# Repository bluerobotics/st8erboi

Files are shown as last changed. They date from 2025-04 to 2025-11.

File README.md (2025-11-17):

<div align="center">

Fillhead

# Fillhead

**Material Injection System Control**






[View Changelog](CHANGELOG.md) • [Download Latest Release](https://github.com/bluerobotics/fillhead/releases/latest)

</div>

---

## Overview

Firmware for the Fillhead material injection system, built on the Teknic ClearCore platform. This firmware provides precision control for material injection operations with dual-motor injector control, pinch valve management, temperature control, and vacuum system monitoring.

**Designed to work with:** [BR Equipment Control App](https://github.com/bluerobotics/br-equipment-control-app) - A Python/Tkinter GUI for controlling and monitoring the Fillhead and other Blue Robotics manufacturing equipment.

## Features

- **Dual injector motors** - Synchronized control of two ganged motors for material injection
- **Pinch valve control** - Two independent motorized pinch valves (vacuum and injection sides)
- **Temperature control** - PID-based heater control with thermocouple feedback
- **Vacuum system** - Pressure monitoring and control with transducer feedback
- **UDP/Ethernet communication** - Network-based control with device discovery
- **USB Serial fallback** - Direct USB communication support
- **Command-based control** - Simple text-based command protocol
- **Real-time telemetry** - Position, temperature, pressure, torque, and status reporting
- **Homing routines** - Automatic homing for injector and pinch valves (tubed/untubed modes)
- **Leak testing** - Automated vacuum leak detection

---

## Building

### Requirements

- **Atmel Studio 7** (Windows) or compatible ARM GCC toolchain
- **Teknic ClearCore libraries** (included in `lib/` folder)
  - `libClearCore`
  - `LwIP` (Lightweight IP stack)

### Build Instructions

1. Open `fillhead.atsln` in Atmel Studio
2. Ensure libraries are properly referenced:
   - `lib/libClearCore/ClearCore.cppproj`
   - `lib/LwIP/LwIP.cppproj`
3. Select build configuration (Debug or Release)
4. Build the solution (F7)

### Output Files

- `Debug/fillhead.bin` - Binary firmware image
- `Debug/fillhead.uf2` - UF2 format for bootloader flashing

## Flashing

### Via BR Equipment Control App (Recommended for Updates)

The easiest way to update firmware on an already-running device is through the [BR Equipment Control App](https://github.com/bluerobotics/br-equipment-control-app):

1. Open the Firmware Manager in the app
2. Select your device
3. Choose the firmware file or download the latest release
4. Click "Update Firmware" - the app handles the entire flashing process automatically

**Note:** Firmware flashing is only supported over USB connections. For initial flashing of a new device, use the bootloader method below.

### Via Bootloader (For Initial Flashing)

For initial flashing of a new device or when the app is not available:

1. Put the ClearCore into bootloader mode (hold button during power-on)
2. Copy `fillhead.uf2` to the mounted bootloader drive
3. The device will automatically reboot with new firmware

### Via Atmel Studio

1. Connect ClearCore via USB
2. Select "Custom Programming Tool" in project settings
3. Build and program (F5)

---

## Communication Protocol

The firmware uses a simple text-based command protocol over UDP or USB serial:

- Commands: `inject <volume> ml`, `feed <distance> mm`, `home_injector`, `set_heater <temp> C`
- Status: `DONE: <command>`, `ERROR: <message>`, `INFO: <message>`
- Telemetry: Periodic status updates with position, temperature, pressure, torque

See the [BR Equipment Control App](https://github.com/bluerobotics/br-equipment-control-app) for full protocol documentation and command reference.

---

## Hardware Configuration

### Motors
- **Injector A**: Primary injector motor (M0)
- **Injector B**: Secondary injector motor (M1) - ganged with A
- **Vacuum Valve**: Pinch valve motor for vacuum side (M2)
- **Injection Valve**: Pinch valve motor for injection side (M3)

### Sensors
- **Thermocouple**: Analog input (A12) for temperature monitoring
- **Vacuum Transducer**: Analog input (A11) for pressure monitoring

### Outputs
- **Heater Relay**: Digital output (IO1) for heater control
- **Vacuum Pump Relay**: Digital output (IO0) for vacuum pump control
- **Vacuum Solenoid Relay**: Digital output (IO5) for solenoid valve control

## Configuration

Key parameters can be configured in `inc/config.h`:

- **Motor parameters**: Steps per mm, velocities, accelerations
- **Temperature control**: PID gains, setpoints, sensor calibration
- **Vacuum control**: Pressure ranges, targets, ramp timeouts
- **Injection parameters**: Piston diameters, speeds, feed rates
- **Homing parameters**: Velocities, accelerations, torque limits for tubed/untubed modes
- **Network settings**: UDP port, packet sizes, telemetry interval

---

## License

This project is licensed under the MIT License - see the [LICENSE](LICENSE) file for details.

Copyright (c) 2025 Blue Robotics

## Contributing

For issues, feature requests, or contributions, please open an issue or pull request on GitHub.

---

<div align="center">

⭐ **Star us on GitHub if you found this useful!**

Made with 💙 by the Blue Robotics team and contributors worldwide

---

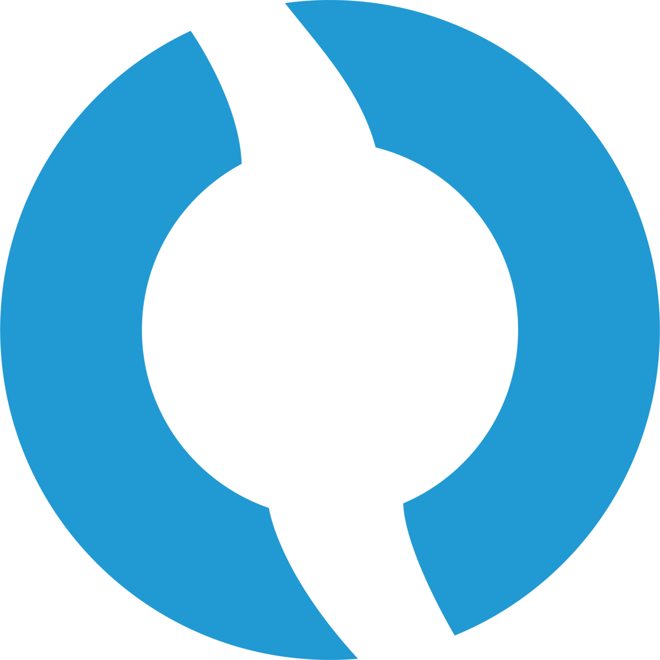
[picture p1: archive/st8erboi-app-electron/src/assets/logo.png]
Blue Robotics


**[bluerobotics.com](https://bluerobotics.com)** | Manufacturing Equipment Control

</div>

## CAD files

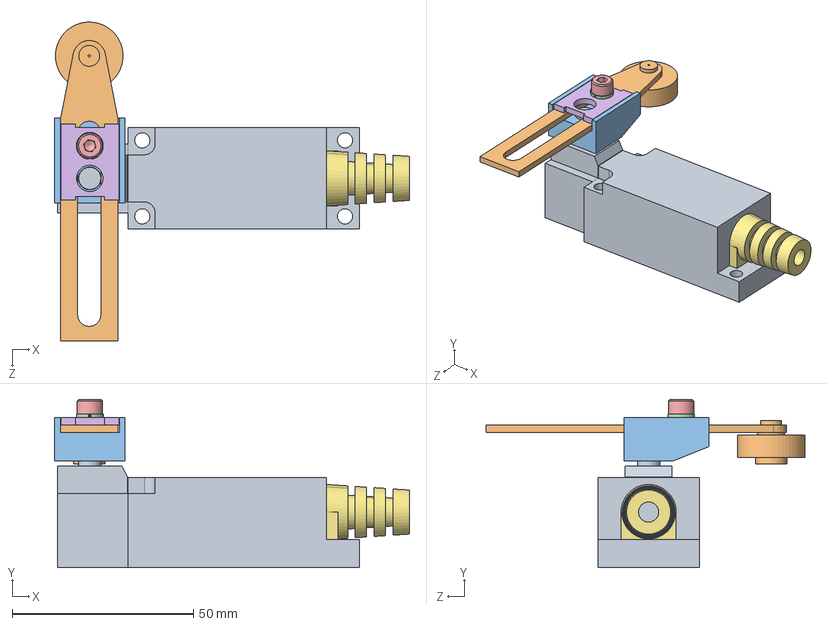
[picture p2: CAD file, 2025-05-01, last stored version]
hardware/st8erboi/User Library-limit switch roller.SLDASM
98.1 x 46.4 x 88.1 mm
User Library-limit switch roller_Limit Switch Body
User Library-limit switch roller_Roller Arm
User Library-limit switch roller_Roller Arm Block
User Library-limit switch roller_4mm LockWasher
User Library-limit switch roller_SHCS M4 x 10mm
User Library-limit switch roller_Roller Clamp Block
User Library-limit switch roller_Cord Grip

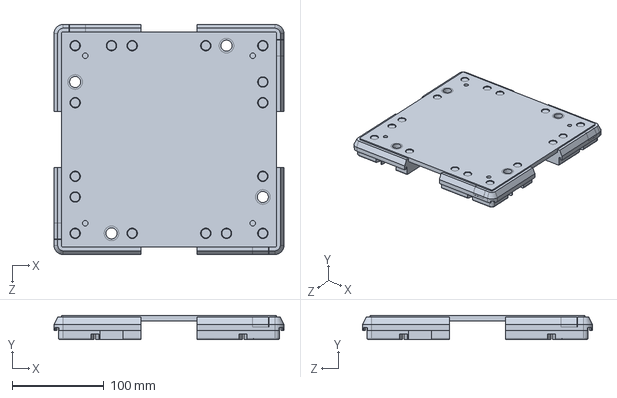
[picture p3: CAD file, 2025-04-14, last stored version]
Conveyer/PALLET-1.SLDPRT
250.0 x 26.4 x 250.0 mm

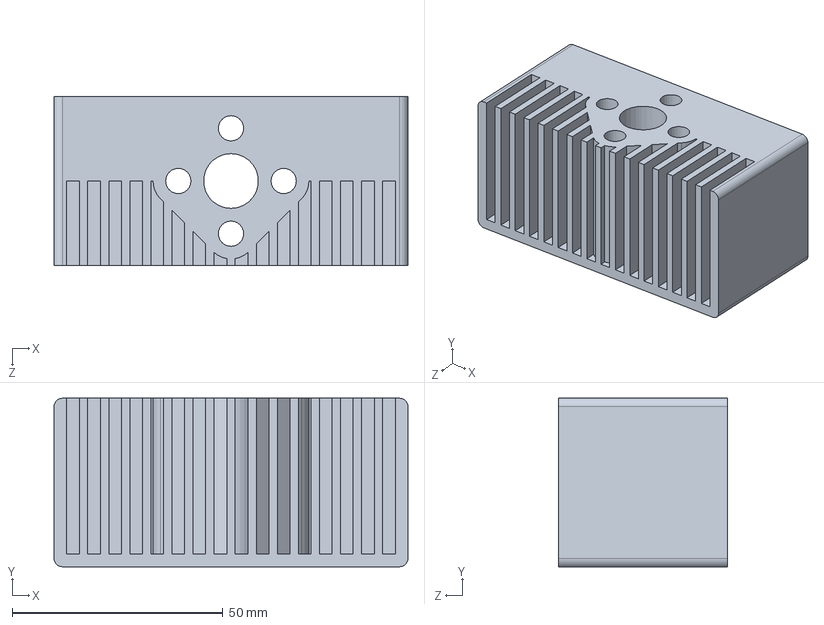
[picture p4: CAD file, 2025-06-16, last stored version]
hardware/st8erboi/fill-head/ST8ERBOI-FILL-HEAD-BLOCK.SLDPRT
84.0 x 40.0 x 40.0 mm

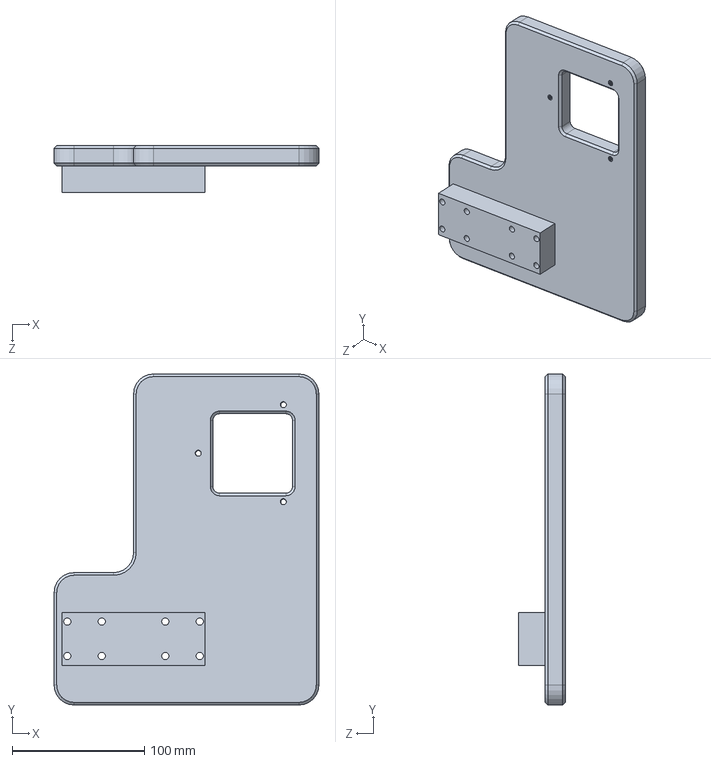
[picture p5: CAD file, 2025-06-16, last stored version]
hardware/st8erboi/NozzleHeadMountingPlate.SLDPRT
200.0 x 250.0 x 35.2 mm

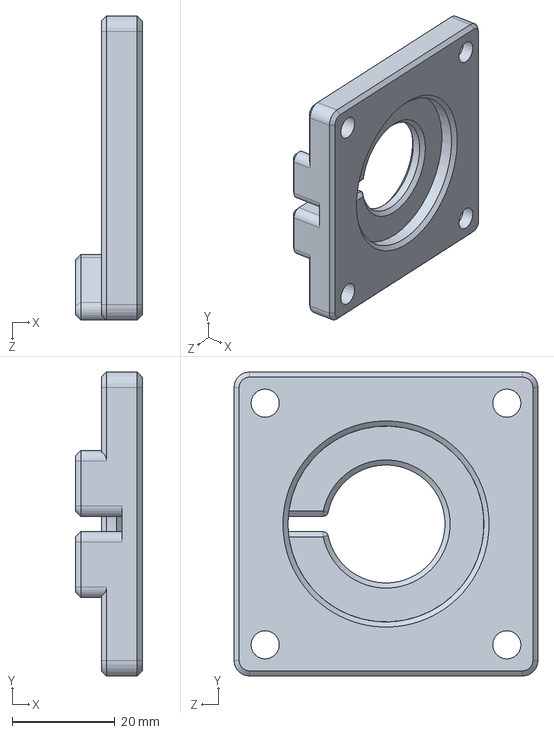
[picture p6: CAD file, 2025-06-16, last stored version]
hardware/st8erboi/pinch-valve/MotorMount.SLDPRT
13.0 x 59.3 x 59.3 mm

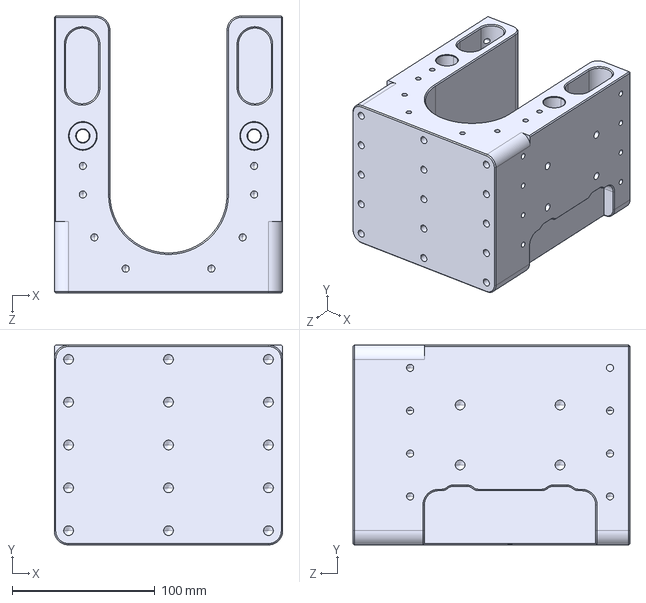
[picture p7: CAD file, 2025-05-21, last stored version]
hardware/st8erboi/release/ST8ERBOI-MCH-P-0001A Megablock.STEP
160.0 x 140.0 x 194.0 mm

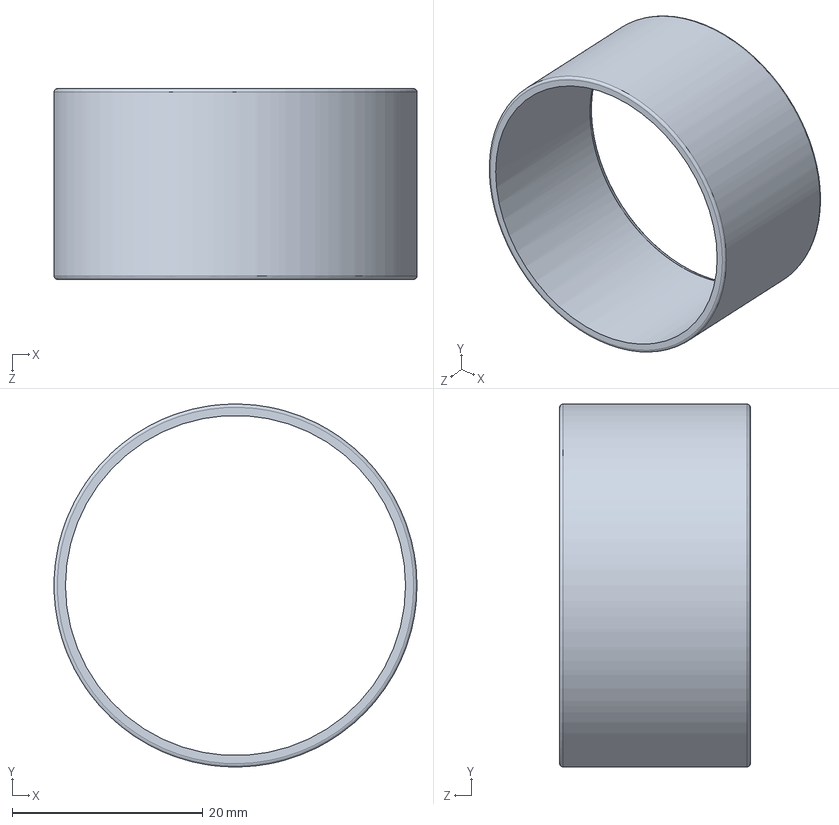
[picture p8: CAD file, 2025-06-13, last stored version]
hardware/st8erboi/t200x/PNG-T200X-ROTOR-FLUX-RING-OVERMOLD.SLDPRT
38.0 x 38.0 x 20.0 mm

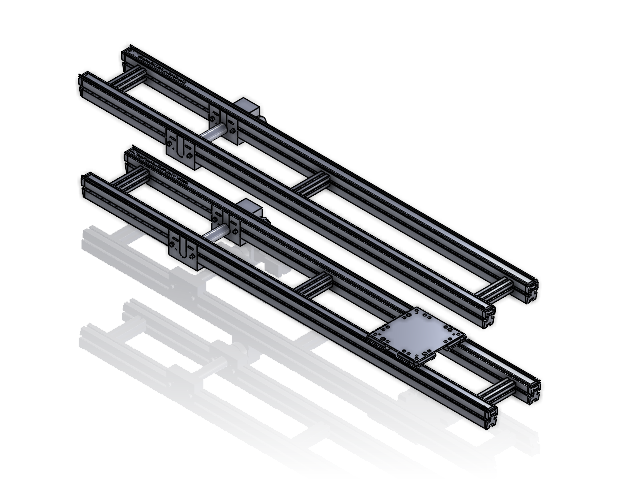
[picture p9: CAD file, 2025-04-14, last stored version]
thruster-line.SLDASM
TEST-1
MOTOR-1
TEST-2
PALLET-1

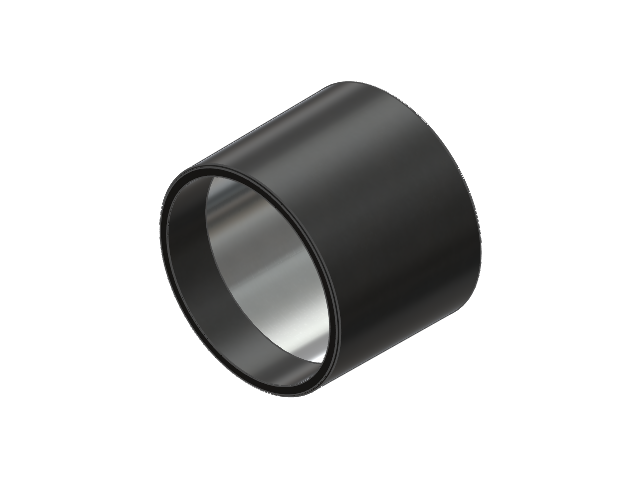
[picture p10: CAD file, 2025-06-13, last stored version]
hardware/st8erboi/t200x/PNG-T200X-B-FLUX-RING.SLDASM
T200X-ROTOR-FLUX-RING-SHELL-OVERMOLD
T200X-ROTOR-FLUX-RING-OVERMOLD

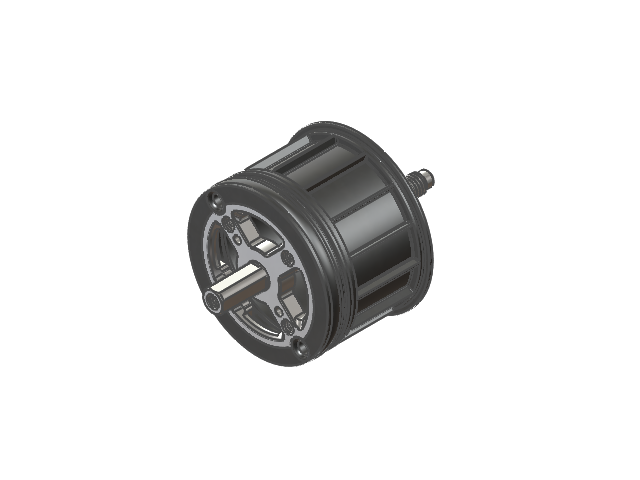
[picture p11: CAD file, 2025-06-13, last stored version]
hardware/st8erboi/t500x/PNG-T500X-B-ROTOR-BASE-CAGE.SLDASM
T500X-B-ROTOR-MAGNET-CAGE
T500X-B-ROTOR-BASE

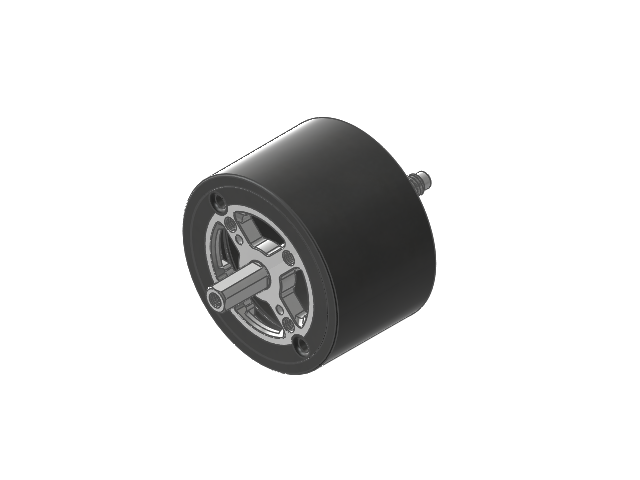
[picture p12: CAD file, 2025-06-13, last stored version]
hardware/st8erboi/t500x/PNG-T500X-B-ROTOR.SLDASM
T500X-B-ROTOR-MAGNET-CAGE
T500X-B-ROTOR-BASE
T500x-B-ROTOR-FLUX-RING-SHELL-OVERMOLD
T500x-B-ROTOR-FLUX-RING-OVERMOLD
t500x-rotor-arc-magnet x 14
Buna-N O-Ring x 2

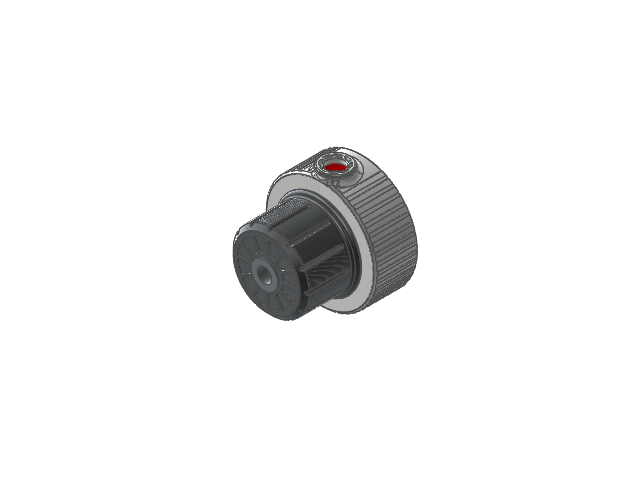
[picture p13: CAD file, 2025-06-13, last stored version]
hardware/st8erboi/t500x/PNG-T500X-B-STATOR.SLDASM
T500X-STATOR-BASE-ESC
T500X-B-STATOR-ENDCAP
T500X-B-STATOR-SHELL
t500x-stator
PCB TEMP
T500X-B-BEARING x 2
T500X-WLP
WLP-SEAL
Buna-N O-Ring x 3
1.5X18.5-Buna-N O-Ring
T500X-B-PLUG x 2

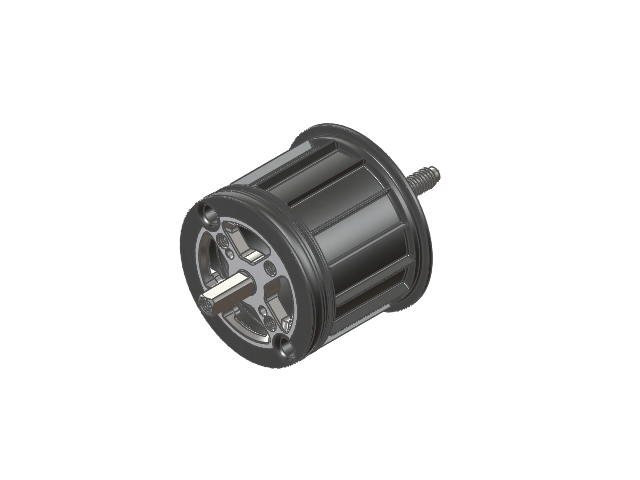
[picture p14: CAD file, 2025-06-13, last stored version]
hardware/st8erboi/t200x/PNG-T200X-B-ROTOR-BASE-CAGE.SLDASM
T200X-B-ROTOR-MAGNET-CAGE
T200X-B-ROTOR-BASE

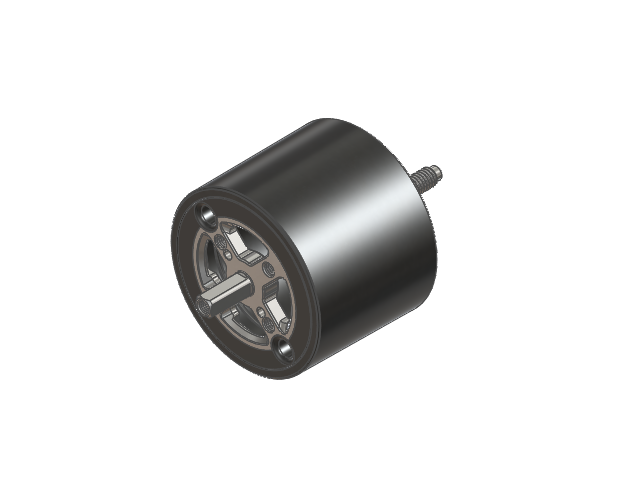
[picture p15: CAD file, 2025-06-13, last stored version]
hardware/st8erboi/t200x/PNG-T200X-B-ROTOR.SLDASM
T200X-B-ROTOR-MAGNET-CAGE
T200X-B-ROTOR-BASE
T200X-ROTOR-FLUX-RING-SHELL-OVERMOLD
T200X-ROTOR-FLUX-RING-OVERMOLD
T200X-ROTOR-ARC-MAGNET x 14
T200X-Buna-N O-Ring x 2

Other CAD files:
hardware/st8erboi/fill-head/Fill Head Assembly.SLDASM
hardware/st8erboi/t500x/PNG-T500X-B-FLUX-RING.SLDASM
hardware/st8erboi/t500x/PNG-T500X-B-NOZZLE.SLDASM
Cartridge Dispenser/1247N208_ABRASION-RESISTANT O-RING.SLDPRT
Cartridge Dispenser/200ml Cartridge.SLDPRT
Cartridge Dispenser/2440K220_FULLY THREADED 4140 STEEL ROD END.SLDPRT
Cartridge Dispenser/3552N260_ BEARING RETAINING LOCKNUT.SLDPRT
Cartridge Dispenser/60645K361_STEEL BALL JOINT ROD END.SLDPRT
Cartridge Dispenser/60645K362_STEEL BALL JOINT ROD END.SLDPRT
Cartridge Dispenser/65945K210_TWO-HAND SAFETY SWITCH SYSTEM.SLDPRT
Cartridge Dispenser/6649K140_HARDENED PRECISION STEEL SHAFT.SLDPRT
Cartridge Dispenser/6649K412_Tapped Linear Motion Shaft.SLDPRT
Cartridge Dispenser/6853N145_ HIGH-SPEED SERVOMOTOR PRECISION FLEXIBLE SHAFT COUPLINGS.SLDPRT
Cartridge Dispenser/78155T140_CART-SMART CASTER.SLDPRT
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

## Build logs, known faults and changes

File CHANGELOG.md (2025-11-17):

# Changelog

All notable changes to the Fillhead firmware will be documented in this file.

## [1.0.0] - 2025-11-17

### Added
- **Initial release**: Fillhead injection system firmware
- **Dual injector motors**: Synchronized control of two ganged injector motors for material injection
- **Pinch valve control**: Two independent pinch valves (vacuum and injection sides) with motorized control
- **Heater control**: PID temperature control with thermocouple feedback and relay output
- **Vacuum system**: Pressure monitoring and control with transducer feedback
- **UDP/Ethernet communication**: Network-based control with device discovery
- **USB Serial support**: Direct USB communication fallback
- **Command-based control**: Simple text-based command protocol for all operations
- **Real-time telemetry**: Position, temperature, pressure, torque, and status reporting
- **Homing routines**: Automatic homing for injector and pinch valves (tubed/untubed modes)
- **Injection control**: Volume-based injection with configurable speeds and piston diameter support
- **Leak testing**: Automated vacuum leak detection with configurable thresholds
- **Error handling**: Comprehensive error reporting and recovery mechanisms

### Features
- **Injector system**: Dual motor synchronized control with configurable pitch and steps/mm
- **Pinch valves**: Motorized pinch valves with separate homing routines for tubed/untubed operation
- **Temperature control**: PID-based heater control with configurable setpoints and gains
- **Vacuum control**: Pressure monitoring with configurable targets and ramp timeouts
- **Material handling**: Support for stator and rotor injection modes with different piston diameters
- **Feed operations**: Configurable feed speeds and accelerations for material handling

### Hardware Support
- Built on Teknic ClearCore platform
- ClearPath motor drivers (M0-M3 connectors)
- Analog inputs for thermocouple and vacuum transducer
- Digital I/O for relay control (heater, vacuum pump, solenoid valve)
- Ethernet connectivity for network communication
- USB serial for direct communication

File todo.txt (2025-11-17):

- integrate new pinch valves once sensors are here
- the command definitions changed for heater and vacuum leak test, update them in the firmware to accept parameters
- there are safety and lockout considerations, test them all

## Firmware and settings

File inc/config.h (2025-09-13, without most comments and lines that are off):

#pragma once
#include "ClearCore.h"
#define LOCAL_PORT                      8888      ///< The UDP port this device listens on for incoming commands.
#define MAX_PACKET_LENGTH               1024      ///< Maximum size in bytes for a single UDP packet. Must be large enough for the longest telemetry string.
#define RX_QUEUE_SIZE                   32        ///< Number of incoming messages that can be buffered before processing.
#define TX_QUEUE_SIZE                   32        ///< Number of outgoing messages that can be buffered before sending.
#define MAX_MESSAGE_LENGTH              MAX_PACKET_LENGTH ///< Maximum size of a single message in the Rx/Tx queues.
#define TELEMETRY_INTERVAL_MS			100       ///< How often (in milliseconds) telemetry data is published to the GUI.
#define STATUS_MESSAGE_BUFFER_SIZE      256       ///< Standard buffer size for composing status and error messages.
#define POST_ABORT_DELAY_MS             100       ///< Delay in milliseconds after an abort command to allow motors to come to a complete stop.
#define INJECTOR_PITCH_MM_PER_REV       5.0f      ///< Linear travel (in mm) of the injector plunger for one full motor revolution.
#define PINCH_PITCH_MM_PER_REV          2.0f      ///< Linear travel (in mm) of the pinch valve actuator for one full motor revolution.
#define PULSES_PER_REV                  800       ///< Number of step pulses required for one full motor revolution (dependent on microstepping settings).
#define STEPS_PER_MM_INJECTOR           (PULSES_PER_REV / INJECTOR_PITCH_MM_PER_REV)   ///< Calculated steps per millimeter for the main injector drive.
#define STEPS_PER_MM_PINCH              (PULSES_PER_REV / PINCH_PITCH_MM_PER_REV)      ///< Calculated steps per millimeter for the pinch valve mechanism.
#define MAX_HOMING_DURATION_MS          100000    ///< Maximum time (in milliseconds) a homing operation is allowed to run before timing out.
#define MOTOR_INJECTOR_A                ConnectorM0 ///< Primary injector motor.
#define MOTOR_INJECTOR_B                ConnectorM1 ///< Secondary, ganged injector motor.
#define MOTOR_VACUUM_VALVE              ConnectorM2 ///< Motor for the pinch valve on the vacuum side.
#define MOTOR_INJECTION_VALVE           ConnectorM3 ///< Motor for the pinch valve on the injection side.
#define PIN_THERMOCOUPLE                ConnectorA12 ///< Analog input for the heater thermocouple.
#define PIN_VACUUM_TRANSDUCER           ConnectorA11 ///< Analog input for the vacuum pressure transducer.
#define PIN_HEATER_RELAY                ConnectorIO1 ///< Digital output to control the heater relay.
#define PIN_VACUUM_RELAY                ConnectorIO0 ///< Digital output to control the vacuum pump relay.
#define PIN_VACUUM_VALVE_RELAY          ConnectorIO5 ///< Digital output to control the vacuum solenoid valve relay.
#define SENSOR_SAMPLE_INTERVAL_MS       100       ///< How often (in ms) to sample temperature and vacuum sensors.
#define EWMA_ALPHA_SENSORS              0.5f      ///< Smoothing factor (alpha) for the Exponentially Weighted Moving Average filter on sensor readings.
#define EWMA_ALPHA_TORQUE               0.2f      ///< Smoothing factor (alpha) for the EWMA filter on motor torque readings.
#define TC_V_REF                        10.0f     ///< ADC reference voltage (10V for ClearCore analog inputs).
#define TC_V_OFFSET                     1.25f     ///< Thermocouple sensor's output voltage at 0 degrees Celsius.
#define TC_GAIN                         200.0f    ///< Conversion factor from volts to degrees Celsius for the thermocouple sensor.
#define PID_UPDATE_INTERVAL_MS          100       ///< How often (in ms) the PID calculation for the heater is performed.
#define PID_PWM_PERIOD_MS               1000      ///< Time window (in ms) for the time-proportioned heater relay control (software PWM).
#define DEFAULT_HEATER_SETPOINT_C       70.0f     ///< Default target temperature in Celsius.
#define DEFAULT_HEATER_KP               60.0f     ///< Default Proportional (P) gain for the PID controller.
#define DEFAULT_HEATER_KI               2.5f      ///< Default Integral (I) gain for the PID controller.
#define DEFAULT_HEATER_KD               40.0f     ///< Default Derivative (D) gain for the PID controller.
#define VAC_V_OUT_MIN                   1.0f      ///< Sensor output voltage at minimum pressure (-14.7 PSIG).
#define VAC_V_OUT_MAX                   5.0f      ///< Sensor output voltage at maximum pressure (15.0 PSIG).
#define VAC_PRESSURE_MIN                -14.7f    ///< Minimum pressure in PSIG that the sensor can read.
#define VAC_PRESSURE_MAX                15.0f     ///< Maximum pressure in PSIG that the sensor can read.
#define VACUUM_PSIG_OFFSET              0.0f      ///< A calibration offset to be added to the raw vacuum sensor reading.
#define DEFAULT_VACUUM_TARGET_PSIG      -14.0f    ///< Default target pressure in PSIG for vacuum operations.
#define DEFAULT_VACUUM_RAMP_TIMEOUT_MS  30000     ///< Default time (in ms) allowed to reach the target pressure before a timeout error.
#define DEFAULT_LEAK_TEST_DELTA_PSIG    0.1f      ///< Default maximum allowed pressure drop during a leak test.
#define DEFAULT_LEAK_TEST_DURATION_MS   10000     ///< Default duration (in ms) for a leak test.
#define VACUUM_SETTLE_TIME_S            2.0f      ///< Time (in s) to let pressure stabilize before starting a leak test measurement.
#define TORQUE_HLFB_AT_POSITION		-9999.0f  ///< Special value from ClearCore HLFB when a move is complete and the motor is at position.
#define MOTOR_DEFAULT_VEL_MAX_MMS           156.25f   ///< Default maximum velocity for motors in mm/s.
#define MOTOR_DEFAULT_ACCEL_MAX_MMSS        625.0f    ///< Default maximum acceleration for motors in mm/s^2.
#define MOTOR_DEFAULT_VEL_MAX_SPS           (int)(MOTOR_DEFAULT_VEL_MAX_MMS * STEPS_PER_MM_INJECTOR) ///< Default max velocity in steps/sec, derived from mm/s.
#define MOTOR_DEFAULT_ACCEL_MAX_SPS2        (int)(MOTOR_DEFAULT_ACCEL_MAX_MMSS * STEPS_PER_MM_INJECTOR) ///< Default max acceleration in steps/sec^2, derived from mm/s^2.
#define PINCH_DEFAULT_VEL_MAX_SPS           (int)(MOTOR_DEFAULT_VEL_MAX_MMS * STEPS_PER_MM_PINCH)      ///< Default max velocity for pinch valves in steps/sec.
#define PINCH_DEFAULT_ACCEL_MAX_SPS2        (int)(MOTOR_DEFAULT_ACCEL_MAX_MMSS * STEPS_PER_MM_PINCH)   ///< Default max acceleration for pinch valves in steps/sec^2.
#define MOVE_START_TIMEOUT_MS           (250)     ///< Time (in ms) to wait for a move to start before flagging a motor error.
#define DEFAULT_INJECTOR_TORQUE_LIMIT       20.0f     ///< Default torque limit (%) for general injector motor operations.
#define DEFAULT_INJECTOR_TORQUE_OFFSET      -2.4f     ///< Default torque offset (%) to account for sensor bias or no-load friction.
#define INJECTOR_HOMING_STROKE_MM           500.0f    ///< Maximum travel distance (mm) during a homing sequence.
#define INJECTOR_HOMING_RAPID_VEL_MMS       5.0f      ///< Velocity (mm/s) for the initial high-speed search for the hard stop.
#define INJECTOR_HOMING_TOUCH_VEL_MMS       1.0f      ///< Velocity (mm/s) for the final, slow-speed precise touch-off.
#define INJECTOR_HOMING_BACKOFF_VEL_MMS     1.0f      ///< Velocity (mm/s) for backing off the hard stop.
#define INJECTOR_HOMING_ACCEL_MMSS          100.0f    ///< Acceleration (mm/s^2) for all homing moves.
#define INJECTOR_HOMING_SEARCH_TORQUE_PERCENT 10.0f   ///< Torque limit (%) used to detect the hard stop.
#define INJECTOR_HOMING_BACKOFF_TORQUE_PERCENT 40.0f  ///< Higher torque limit (%) for the back-off move to prevent stalling.
#define INJECTOR_HOMING_BACKOFF_MM          1.0f      ///< Distance (mm) to back off from the hard stop.
#define PINCH_HOMING_UNTUBED_STROKE_MM              50.0f  ///< Max travel (mm) for untubed homing.
#define PINCH_HOMING_UNTUBED_UNIFIED_VEL_MMS        1.0f   ///< Unified velocity (mm/s) for all moves during untubed homing.
#define PINCH_HOMING_UNTUBED_ACCEL_MMSS             100.0f ///< Acceleration (mm/s^2) for untubed homing.
#define PINCH_HOMING_UNTUBED_SEARCH_TORQUE_PERCENT  15.0f  ///< Torque limit (%) for detecting the hard stop without tubing.
#define PINCH_HOMING_UNTUBED_BACKOFF_TORQUE_PERCENT 50.0f  ///< Higher torque (%) for the back-off move.
#define PINCH_VALVE_UNTUBED_FINAL_OFFSET_MM         9.0f   ///< Final offset distance (mm) from the hard stop, defining the "open" position.
#define PINCH_VALVE_HOMING_BACKOFF_MM_UNTUBED 0.5f         ///< Back-off distance (mm) for untubed homing.
#define PINCH_HOMING_TUBED_STROKE_MM              50.0f  ///< Max travel (mm) for tubed homing.
#define PINCH_HOMING_TUBED_UNIFIED_VEL_MMS        1.0f   ///< Unified velocity (mm/s) for all moves during tubed homing.
#define PINCH_HOMING_TUBED_ACCEL_MMSS             100.0f ///< Acceleration (mm/s^2) for tubed homing.
#define PINCH_HOMING_TUBED_SEARCH_TORQUE_PERCENT  60.0f  ///< Higher torque limit (%) needed to fully pinch the tube.
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

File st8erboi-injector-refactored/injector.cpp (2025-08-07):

#include "injector.h"

// String representations for enums
const char *Injector::MainStateNames[MAIN_STATE_COUNT] = { "STANDBY_MODE", "DISABLED_MODE" };
const char *Injector::HomingStateNames[HOMING_STATE_COUNT] = { "HOMING_NONE", "HOMING_MACHINE", "HOMING_CARTRIDGE", "HOMING_PINCH" };
const char *Injector::HomingPhaseNames[HOMING_PHASE_COUNT] = { "IDLE", "STARTING_MOVE", "RAPID_MOVE", "BACK_OFF", "TOUCH_OFF", "RETRACT", "COMPLETE", "ERROR" };
const char *Injector::FeedStateNames[FEED_STATE_COUNT] = { "FEED_NONE", "FEED_STANDBY", "FEED_INJECT_STARTING", "FEED_INJECT_ACTIVE", "FEED_INJECT_PAUSED", "FEED_INJECT_RESUMING", "FEED_PURGE_STARTING", "FEED_PURGE_ACTIVE", "FEED_PURGE_PAUSED", "FEED_PURGE_RESUMING", "FEED_MOVING_TO_HOME", "FEED_MOVING_TO_RETRACT", "FEED_INJECTION_CANCELLED", "FEED_INJECTION_COMPLETED" };
const char *Injector::ErrorStateNames[ERROR_STATE_COUNT] = { "ERROR_NONE", "ERROR_MANUAL_ABORT", "ERROR_TORQUE_ABORT", "ERROR_MOTION_EXCEEDED_ABORT", "ERROR_NO_CARTRIDGE_HOME", "ERROR_NO_MACHINE_HOME", "ERROR_HOMING_TIMEOUT", "ERROR_HOMING_NO_TORQUE_RAPID", "ERROR_HOMING_NO_TORQUE_TOUCH", "ERROR_INVALID_INJECTION", "ERROR_NOT_HOMED", "ERROR_INVALID_PARAMETERS", "ERROR_MOTORS_DISABLED" };
const char *Injector::HeaterStateNames[HEATER_STATE_COUNT] = { "OFF", "MANUAL", "PID" };

// Constructor
Injector::Injector() {
	mainState = STANDBY_MODE;
	homingState = HOMING_NONE;
	currentHomingPhase = HOMING_PHASE_IDLE;
	feedState = FEED_STANDBY;
	errorState = ERROR_NONE;
	homingMachineDone = false;
	homingCartridgeDone = false;
	homingPinchDone = false;
	homingPinch2Done = false;
	homingPinch3Done = false;
	feedingDone = true;
	jogDone = true;
	homingStartTime = 0;
	
	peerIp = IpAddress();
	peerDiscovered = false;
	guiDiscovered = false;
	guiPort = 0;
	
	lastGuiTelemetryTime = 0;
	
	injectorMotorsTorqueLimit   = 20.0f;
	injectorMotorsTorqueOffset = -2.4f;
	smoothedTorqueValue0 = 0.0f;
	smoothedTorqueValue1 = 0.0f;
	smoothedTorqueValue2 = 0.0f;
	smoothedTorqueValue3 = 0.0f;
	firstTorqueReading0 = true;
	firstTorqueReading1 = true;
	firstTorqueReading2 = true;
	firstTorqueReading3 = true;
	motorsAreEnabled = false;

	heaterOn = false;
	vacuumOn = false;
	temperatureCelsius = 0.0f;
	vacuumPressurePsig = 0.0f;
	smoothedVacuumPsig = 0.0f;
	firstVacuumReading = true;
	smoothedTemperatureCelsius = 0.0f;
	firstTempReading = true;
	lastSensorSampleTime = 0;

	machineHomeReferenceSteps = 0;
	cartridgeHomeReferenceSteps = 0;
	pinchHomeReferenceSteps = 0;
	homingDefaultBackoffSteps = 200;
	
	feedDefaultTorquePercent = 30;
	feedDefaultVelocitySPS = 1000;
	feedDefaultAccelSPS2 = 10000;
	
	vacuumValveOn = false;
	
	pid_setpoint = 70.0f;
	pid_kp = 60;
	pid_ki = 2.5;
	pid_kd = 40;
	resetPid();

	fullyResetActiveDispenseOperation();
	
	activeFeedCommand = nullptr;
	activeJogCommand = nullptr;

	// Initialize queue pointers
	m_rxQueueHead = 0;
	m_rxQueueTail = 0;
	m_txQueueHead = 0;
	m_txQueueTail = 0;
}

void Injector::setup() {
	setupSerial();
	setupEthernet();
	setupMotors();
	setupPeripherals();
}

void Injector::setupPeripherals(void) {
	PIN_THERMOCOUPLE.Mode(Connector::INPUT_ANALOG);
	PIN_HEATER_RELAY.Mode(Connector::OUTPUT_DIGITAL);
	PIN_VACUUM_RELAY.Mode(Connector::OUTPUT_DIGITAL);
	PIN_VACUUM_TRANSDUCER.Mode(Connector::INPUT_ANALOG);
	PIN_VACUUM_VALVE_RELAY.Mode(Connector::OUTPUT_DIGITAL);
	
	PIN_HEATER_RELAY.State(false);
	PIN_VACUUM_RELAY.State(false);
	PIN_VACUUM_VALVE_RELAY.State(false);
}

void Injector::updateTemperature(void) {
	uint16_t adc_val = PIN_THERMOCOUPLE.State();
	float voltage_from_sensor = (float)adc_val * (TC_V_REF / 4095.0f);
	
	float raw_celsius = (voltage_from_sensor - TC_V_OFFSET) * TC_GAIN;

	if (firstTempReading) {
		smoothedTemperatureCelsius = raw_celsius;
		firstTempReading = false;
		} else {
		smoothedTemperatureCelsius = (EWMA_ALPHA_SENSORS * raw_celsius) + ((1.0f - EWMA_ALPHA_SENSORS) * smoothedTemperatureCelsius);
	}

	temperatureCelsius = smoothedTemperatureCelsius;
}

void Injector::updatePid() {
	if (heaterState != HEATER_PID_ACTIVE) {
		if (pid_output != 0.0f) {
			pid_output = 0.0f;
		}
		return;
	}

	uint32_t now = Milliseconds();
	float time_change_ms = (float)(now - pid_last_time);

	if (time_change_ms < 10.0f) {
		return;
	}

	float error = pid_setpoint - temperatureCelsius;
	pid_integral += error * (time_change_ms / 1000.0f);
	float derivative = ((error - pid_last_error) * 1000.0f) / time_change_ms;
	
	pid_output = (pid_kp * error) + (pid_ki * pid_integral) + (pid_kd * derivative);

	if (pid_output > 100.0f) pid_output = 100.0f;
	if (pid_output < 0.0f) pid_output = 0.0f;
	if (pid_integral > 100.0f / pid_ki) pid_integral = 100.0f / pid_ki;
	if (pid_integral < 0.0f) pid_integral = 0.0f;

	pid_last_error = error;
	pid_last_time = now;

	uint32_t on_duration_ms = (uint32_t)(PID_PWM_PERIOD_MS * (pid_output / 100.0f));
	PIN_HEATER_RELAY.State((now % PID_PWM_PERIOD_MS) < on_duration_ms);
}

void Injector::updateVacuum(void) {
	uint16_t adc_val = PIN_VACUUM_TRANSDUCER.State();
	float measured_voltage = (float)adc_val * (TC_V_REF / 4095.0f);

	float voltage_span = VAC_V_OUT_MAX - VAC_V_OUT_MIN;
	float pressure_span = VAC_PRESSURE_MAX - VAC_PRESSURE_MIN;
	float voltage_percent = (measured_voltage - VAC_V_OUT_MIN) / voltage_span;

	float raw_psig = (voltage_percent * pressure_span) + VAC_PRESSURE_MIN;

	if (firstVacuumReading) {
		smoothedVacuumPsig = raw_psig;
		firstVacuumReading = false;
		} else {
		smoothedVacuumPsig = (EWMA_ALPHA_SENSORS * raw_psig) + ((1.0f - EWMA_ALPHA_SENSORS) * smoothedVacuumPsig);
	}

	vacuumPressurePsig = smoothedVacuumPsig + VACUUM_PSIG_OFFSET;

	if (vacuumPressurePsig < VAC_PRESSURE_MIN) vacuumPressurePsig = VAC_PRESSURE_MIN;
	if (vacuumPressurePsig > VAC_PRESSURE_MAX) vacuumPressurePsig = VAC_PRESSURE_MAX;
}



void Injector::onHomingMachineDone(){
	homingMachineDone = true;
}

void Injector::onHomingCartridgeDone(){
	homingCartridgeDone = true;
}

void Injector::onHomingPinchDone(){
	homingPinchDone = true;
}

void Injector::onFeedingDone(){
	feedingDone = true;
}

void Injector::onJogDone(){
	jogDone = true;
}

void Injector::resetPid() {
	pid_integral = 0.0f;
	pid_last_error = 0.0f;
	pid_output = 0.0f;
	pid_last_time = Milliseconds();
}

void Injector::updateState() {
	if (mainState == DISABLED_MODE) {
		return;
	}

	// --- Homing State Logic ---
	if (homingState != HOMING_NONE) {
		if (currentHomingPhase == HOMING_PHASE_COMPLETE || currentHomingPhase == HOMING_PHASE_ERROR) {
			if (currentHomingPhase == HOMING_PHASE_COMPLETE) {
				char doneMsg[64];
				const char* commandStr = "UNKNOWN_HOME";
				if (homingState == HOMING_MACHINE) commandStr = CMD_STR_MACHINE_HOME_MOVE;
				else if (homingState == HOMING_CARTRIDGE) commandStr = CMD_STR_CARTRIDGE_HOME_MOVE;
				else if (homingState == HOMING_PINCH) commandStr = CMD_STR_PINCH_HOME_MOVE;
				snprintf(doneMsg, sizeof(doneMsg), "%s complete.", commandStr);
				sendStatus(STATUS_PREFIX_DONE, doneMsg);
				} else {
				sendStatus(STATUS_PREFIX_ERROR,"Homing sequence ended with error.");
			}
			homingState = HOMING_NONE;
			currentHomingPhase = HOMING_PHASE_IDLE;
			} else {
			uint32_t current_time = Milliseconds();
			if (current_time - homingStartTime > MAX_HOMING_DURATION_MS) {
				sendStatus(STATUS_PREFIX_ERROR, "Homing Error: Timeout. Aborting.");
				abortInjectorMove();
				errorState = ERROR_HOMING_TIMEOUT;
				currentHomingPhase = HOMING_PHASE_ERROR;
			}
		}

		// REFACTORED: State machine for independent pinch homing
		if (homingState == HOMING_PINCH) {
			// Check motor M2 (Pinch 1)
			if (!homingPinch2Done) {
				float torque2 = getSmoothedTorqueEWMA(&ConnectorM2, &smoothedTorqueValue2, &firstTorqueReading2);
				bool stalled_on_torque = (torque2 != TORQUE_SENTINEL_INVALID_VALUE && torque2 > injectorMotorsTorqueLimit);
				bool finished_move = !ConnectorM2.StatusReg().bit.StepsActive;

				if (stalled_on_torque || finished_move) {
					ConnectorM2.MoveStopAbrupt();
					ConnectorM2.PositionRefSet(0);
					homingPinch2Done = true;
					sendStatus(STATUS_PREFIX_INFO, "Pinch motor 2 (M2) has homed.");
				}
			}

			// Check motor M3 (Pinch 2)
			if (!homingPinch3Done) {
				float torque3 = getSmoothedTorqueEWMA(&ConnectorM3, &smoothedTorqueValue3, &firstTorqueReading3);
				bool stalled_on_torque = (torque3 != TORQUE_SENTINEL_INVALID_VALUE && torque3 > injectorMotorsTorqueLimit);
				bool finished_move = !ConnectorM3.StatusReg().bit.StepsActive;

				if (stalled_on_torque || finished_move) {
					ConnectorM3.MoveStopAbrupt();
					ConnectorM3.PositionRefSet(0);
					homingPinch3Done = true;
					sendStatus(STATUS_PREFIX_INFO, "Pinch motor 3 (M3) has homed.");
				}
			}

			// If both are done, complete the overall homing operation
			if (homingPinch2Done && homingPinch3Done) {
				onHomingPinchDone();
				errorState = ERROR_NONE;
				currentHomingPhase = HOMING_PHASE_COMPLETE;
			}
		}
		// State machine for the original multi-phase homing (Machine and Cartridge)
		else if (homingState == HOMING_MACHINE || homingState == HOMING_CARTRIDGE) {
			int direction = (homingState == HOMING_MACHINE) ? -1 : 1;

			switch (currentHomingPhase) {
				case HOMING_PHASE_STARTING_MOVE: {
					uint32_t current_time = Milliseconds();
					if (current_time - homingStartTime > 50) {
						if (checkInjectorMoving()) {
							sendStatus(STATUS_PREFIX_START, "Homing: Move started. Entering RAPID_MOVE phase.");
							currentHomingPhase = HOMING_PHASE_RAPID_MOVE;
							} else {
							sendStatus(STATUS_PREFIX_ERROR, "Homing Error: Motor failed to start moving.");
							errorState = ERROR_HOMING_NO_TORQUE_RAPID;
							currentHomingPhase = HOMING_PHASE_ERROR;
						}
					}
					break;
				}
				case HOMING_PHASE_RAPID_MOVE:
				case HOMING_PHASE_TOUCH_OFF: {
					if (checkInjectorTorqueLimit()) {
						if (currentHomingPhase == HOMING_PHASE_RAPID_MOVE) {
							sendStatus(STATUS_PREFIX_INFO, "Homing: Torque (RAPID). Backing off.");
							currentHomingPhase = HOMING_PHASE_BACK_OFF;
							long back_off_s = -direction * homingDefaultBackoffSteps;
							moveInjectorMotors(back_off_s, back_off_s, (int)homing_torque_percent_param, homing_actual_touch_sps, homing_actual_accel_sps2);
							} else { // TOUCH_OFF
							sendStatus(STATUS_PREFIX_INFO, "Homing: Torque (TOUCH_OFF). Zeroing & Retracting.");
							if (homingState == HOMING_MACHINE) {
								machineHomeReferenceSteps = ConnectorM0.PositionRefCommanded();
								sendStatus(STATUS_PREFIX_INFO, "Machine home reference point set.");
								} else if (homingState == HOMING_CARTRIDGE) {
								cartridgeHomeReferenceSteps = ConnectorM0.PositionRefCommanded();
								sendStatus(STATUS_PREFIX_INFO, "Cartridge home reference point set.");
							}
							currentHomingPhase = HOMING_PHASE_RETRACT;
							long retract_s = -direction * homing_actual_retract_steps;
							moveInjectorMotors(retract_s, retract_s, (int)homing_torque_percent_param, homing_actual_rapid_sps, homing_actual_accel_sps2);
						}
						} else if (!checkInjectorMoving()) {
						const char* msg = currentHomingPhase == HOMING_PHASE_RAPID_MOVE ? "Homing Err: No torque in RAPID." : "Homing Err: No torque in TOUCH_OFF.";
						sendStatus(STATUS_PREFIX_ERROR, msg);
						errorState = currentHomingPhase == HOMING_PHASE_RAPID_MOVE ? ERROR_HOMING_NO_TORQUE_RAPID : ERROR_HOMING_NO_TORQUE_TOUCH;
						currentHomingPhase = HOMING_PHASE_ERROR;
					}
					break;
				}
				case HOMING_PHASE_BACK_OFF: {
					if (!checkInjectorMoving()) {
						sendStatus(STATUS_PREFIX_INFO, "Homing: Back-off done. Touching off.");
						currentHomingPhase = HOMING_PHASE_TOUCH_OFF;
						long touch_off_move_length = homingDefaultBackoffSteps * 2;
						long final_touch_off_move_steps = direction * touch_off_move_length;
						moveInjectorMotors(final_touch_off_move_steps, final_touch_off_move_steps, (int)homing_torque_percent_param, homing_actual_touch_sps, homing_actual_accel_sps2);
					}
					break;
				}
				case HOMING_PHASE_RETRACT: {
					if (!checkInjectorMoving()) {
						sendStatus(STATUS_PREFIX_INFO, "Homing: RETRACT complete. Success.");
						if (homingState == HOMING_MACHINE) onHomingMachineDone();
						else if (homingState == HOMING_CARTRIDGE) onHomingCartridgeDone();
						errorState = ERROR_NONE;
						currentHomingPhase = HOMING_PHASE_COMPLETE;
					}
					break;
				}
				default: break;
			}
		}
	}

	// --- Feed State Logic ---
	if (active_dispense_INJECTION_ongoing) {
		if (feedState == FEED_INJECT_ACTIVE || feedState == FEED_PURGE_ACTIVE ||
		feedState == FEED_MOVING_TO_HOME || feedState == FEED_MOVING_TO_RETRACT ||
		feedState == FEED_INJECT_RESUMING || feedState == FEED_PURGE_RESUMING) {
			if (checkInjectorTorqueLimit()) {
				errorState = ERROR_TORQUE_ABORT;
				sendStatus(STATUS_PREFIX_ERROR,"FEED_MODE: Torque limit! Operation stopped.");
				finalizeAndResetActiveDispenseOperation(false);
				feedState = FEED_STANDBY;
				feedingDone = true;
			}
		}

		if (!checkInjectorMoving()) {
			if (!feedingDone) {
				if (feedState == FEED_INJECT_ACTIVE || feedState == FEED_PURGE_ACTIVE) {
					if (active_op_steps_per_ml > 0.0001f) {
						long steps_moved_this_segment = ConnectorM0.PositionRefCommanded() - active_op_segment_initial_axis_steps;
						float segment_dispensed_ml = (float)fabs(steps_moved_this_segment) / active_op_steps_per_ml;
						active_op_total_dispensed_ml += segment_dispensed_ml;
					}
					last_completed_dispense_ml = active_op_total_dispensed_ml;
					feedState = FEED_INJECTION_COMPLETED;
					} else if (feedState == FEED_MOVING_TO_HOME || feedState == FEED_MOVING_TO_RETRACT) {
					feedState = FEED_INJECTION_COMPLETED;
				}
				
				if (feedState == FEED_INJECTION_COMPLETED) {
					if (activeFeedCommand != nullptr) {
						char doneMsg[64];
						snprintf(doneMsg, sizeof(doneMsg), "%s complete.", activeFeedCommand);
						sendStatus(STATUS_PREFIX_DONE, doneMsg);
					}
					feedingDone = true;
					onFeedingDone();
					finalizeAndResetActiveDispenseOperation(true);
					feedState = FEED_STANDBY;
				}
			}
			} else {
			if (feedState == FEED_INJECT_STARTING) {
				feedState = FEED_INJECT_ACTIVE;
				active_op_segment_initial_axis_steps = ConnectorM0.PositionRefCommanded();
				sendStatus(STATUS_PREFIX_INFO, "Feed Op: Inject Active.");
				} else if (feedState == FEED_PURGE_STARTING) {
				feedState = FEED_PURGE_ACTIVE;
				active_op_segment_initial_axis_steps = ConnectorM0.PositionRefCommanded();
				sendStatus(STATUS_PREFIX_INFO, "Feed Op: Purge Active.");
				} else if (feedState == FEED_INJECT_RESUMING) {
				feedState = FEED_INJECT_ACTIVE;
				active_op_segment_initial_axis_steps = ConnectorM0.PositionRefCommanded();
				sendStatus(STATUS_PREFIX_INFO, "Feed Op: Inject Resumed, Active.");
				} else if (feedState == FEED_PURGE_RESUMING) {
				feedState = FEED_PURGE_ACTIVE;
				active_op_segment_initial_axis_steps = ConnectorM0.PositionRefCommanded();
				sendStatus(STATUS_PREFIX_INFO, "Feed Op: Purge Resumed, Active.");
			}
		}

		if ((feedState == FEED_INJECT_PAUSED || feedState == FEED_PURGE_PAUSED) &&
		!feedingDone && !checkInjectorMoving()) {
			long current_pos = ConnectorM0.PositionRefCommanded();
			long steps_moved_this_segment = current_pos - active_op_segment_initial_axis_steps;
			if (active_op_steps_per_ml > 0.0001f) {
				float segment_dispensed_ml = fabs(steps_moved_this_segment) / active_op_steps_per_ml;
				active_op_total_dispensed_ml += segment_dispensed_ml;
				long total_steps_dispensed = (long)(active_op_total_dispensed_ml * active_op_steps_per_ml);
				active_op_remaining_steps = active_op_total_target_steps - total_steps_dispensed;
				if (active_op_remaining_steps < 0) active_op_remaining_steps = 0;
			}
			feedingDone = true;
			sendStatus(STATUS_PREFIX_INFO, "Feed Op: Operation Paused. Waiting for Resume/Cancel.");
		}
	}

	// --- Jog State Logic ---
	if (!jogDone) {
		if (checkInjectorTorqueLimit()) {
			abortInjectorMove();
			errorState = ERROR_TORQUE_ABORT;
			sendStatus(STATUS_PREFIX_INFO, "JOG: Torque limit, returning to STANDBY.");
			onJogDone();
			if (activeJogCommand != nullptr) {
				activeJogCommand = nullptr;
			}
			} else if (!checkInjectorMoving()) {
			onJogDone();
			if (activeJogCommand != nullptr) {
				char doneMsg[64];
				snprintf(doneMsg, sizeof(doneMsg), "%s complete.", activeJogCommand);
				sendStatus(STATUS_PREFIX_DONE, doneMsg);
				activeJogCommand = nullptr;
			}
		}
	}
}

void Injector::loop() {
	// 1. Read incoming UDP packets and place them in the Rx queue
	processUdp();

	// 2. Process ONE message from the Rx queue
	processRxQueue();

	// 3. Send ONE message from the Tx queue
	processTxQueue();

	// 4. Update state machine
	updateState();

	// 5. Handle periodic tasks
	uint32_t now = Milliseconds();
	if (now - lastPidUpdateTime >= PID_UPDATE_INTERVAL_MS) {
		lastPidUpdateTime = now;
		updatePid();
	}

	if (now - lastGuiTelemetryTime >= 100 && guiDiscovered) {
		lastGuiTelemetryTime = now;
		sendGuiTelemetry();
	}

	if (now - lastSensorSampleTime >= SENSOR_SAMPLE_INTERVAL_MS) {
		lastSensorSampleTime = now;
		updateTemperature();
		updateVacuum();
	}
}

Injector injector;

int main(void) {
	injector.setup();

	while (true) {
		injector.loop();
	}
}


// Implementations for string converters
const char* Injector::mainStateStr() const { return MainStateNames[mainState]; }
const char* Injector::homingStateStr() const { return HomingStateNames[homingState]; }
const char* Injector::homingPhaseStr() const { return HomingPhaseNames[currentHomingPhase]; }
const char* Injector::feedStateStr() const { return FeedStateNames[feedState]; }
const char* Injector::errorStateStr() const { return ErrorStateNames[errorState]; }
const char* Injector::heaterStateStr() const { return HeaterStateNames[heaterState]; }

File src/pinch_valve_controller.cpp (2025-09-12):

/**
 * @file pinch_valve_controller.cpp
 * @author Eldin Miller-Stead
 * @date September 10, 2025
 * @brief Implements the controller for a single motorized pinch valve.
 *
 * @details This file provides the concrete implementation for the `PinchValve` class.
 * It contains the logic for the state machines that manage homing, opening, closing,
 * and jogging operations, as well as motor control and torque monitoring.
 */
#include "pinch_valve_controller.h"
#include "fillhead.h"
#include <stdio.h>
#include <stdlib.h>
#include <math.h>

/**
 * @brief Constructs the PinchValve controller.
 */
PinchValve::PinchValve(const char* name, MotorDriver* motor, Fillhead* controller) :
    m_name(name),
    m_motor(motor),
    m_controller(controller),
    m_state(VALVE_NOT_HOMED), // Default state is now NOT_HOMED
    m_homingPhase(HOMING_PHASE_IDLE),
    m_opPhase(PHASE_IDLE),
    m_moveType(MOVE_TYPE_NONE), // Initialize move type
    m_moveStartTime(0),
    m_isHomed(false),
    m_homingStartTime(0),
    m_torqueLimit(0.0f),
    m_smoothedTorque(0.0f),
    m_firstTorqueReading(true) {
}

/**
 * @brief Initializes the motor hardware for the pinch valve.
 */
void PinchValve::setup() {
	m_motor->HlfbMode(MotorDriver::HLFB_MODE_HAS_BIPOLAR_PWM);
	m_motor->HlfbCarrier(MotorDriver::HLFB_CARRIER_482_HZ);
	m_motor->VelMax(PINCH_DEFAULT_VEL_MAX_SPS);
	m_motor->AccelMax(PINCH_DEFAULT_ACCEL_MAX_SPS2);
	m_motor->EnableRequest(true);
}

/**
 * @brief The main update loop for the valve's state machine.
 */
void PinchValve::updateState() {
    // Check for motor faults first, as this is a critical hardware issue.
    if (isInFault() && m_state != VALVE_ERROR) {
        m_state = VALVE_ERROR;
        m_isHomed = false; // Lost homed status due to error
        reportEvent(STATUS_PREFIX_ERROR, "Motor fault detected.");
    }

    switch (m_state) {
        case VALVE_HOMING: {
			// Homing logic remains the same...
			if (Milliseconds() - m_homingStartTime > MAX_HOMING_DURATION_MS) {
				abort();
				m_state = VALVE_ERROR;
				m_isHomed = false; // Lost homed status due to error
				m_homingPhase = HOMING_PHASE_IDLE;
				char errorMsg[128];
				snprintf(errorMsg, sizeof(errorMsg), "%s homing timeout.", m_name);
				reportEvent(STATUS_PREFIX_ERROR, errorMsg);
				return;
			}
			
			switch (m_homingPhase) {
				case INITIAL_BACKOFF_START:
					reportEvent(STATUS_PREFIX_INFO, "Homing: Performing initial backoff.");
					m_torqueLimit = m_homingBackoffTorque;
					moveSteps(-m_homingBackoffSteps, m_homingUnifiedSps, m_homingAccelSps2);
					m_homingPhase = INITIAL_BACKOFF_WAIT_TO_START;
					break;
				case INITIAL_BACKOFF_WAIT_TO_START:
					if (m_motor->StatusReg().bit.StepsActive) {
						m_homingPhase = INITIAL_BACKOFF_MOVING;
					} else if (Milliseconds() - m_homingStartTime > 500) {
						 reportEvent(STATUS_PREFIX_INFO, "Homing: Initial backoff did not start, proceeding.");
						 m_homingPhase = RAPID_SEARCH_START;
					}
					break;
				case INITIAL_BACKOFF_MOVING:
					if (checkTorqueLimit() || !m_motor->StatusReg().bit.StepsActive) {
						m_homingPhase = RAPID_SEARCH_START;
					}
					break;
				case RAPID_SEARCH_START:
					reportEvent(STATUS_PREFIX_INFO, "Homing: Starting rapid search.");
					m_torqueLimit = m_homingSearchTorque;
					moveSteps(m_homingDistanceSteps, m_homingUnifiedSps, m_homingAccelSps2);
					m_homingPhase = RAPID_SEARCH_WAIT_TO_START;
					break;
				case RAPID_SEARCH_WAIT_TO_START:
					if (m_motor->StatusReg().bit.StepsActive) m_homingPhase = RAPID_SEARCH_MOVING;
					break;
				case RAPID_SEARCH_MOVING:
					if (checkTorqueLimit()) {
						m_homingPhase = BACKOFF_START;
					} else if (!m_motor->StatusReg().bit.StepsActive) {
						m_state = VALVE_ERROR;
						m_isHomed = false; // Lost homed status due to error
						reportEvent(STATUS_PREFIX_ERROR, "Homing failed: move finished before hard stop.");
					}
					break;
				case BACKOFF_START:
					reportEvent(STATUS_PREFIX_INFO, "Homing: Backing off hard stop.");
					m_torqueLimit = m_homingBackoffTorque;
					moveSteps(-m_homingBackoffSteps, m_homingUnifiedSps, m_homingAccelSps2);
					m_homingPhase = BACKOFF_WAIT_TO_START;
					break;
				case BACKOFF_WAIT_TO_START:
					if (m_motor->StatusReg().bit.StepsActive) m_homingPhase = BACKOFF_MOVING;
					break;
				case BACKOFF_MOVING:
					if (!m_motor->StatusReg().bit.StepsActive) m_homingPhase = SLOW_SEARCH_START;
					break;
				case SLOW_SEARCH_START:
					reportEvent(STATUS_PREFIX_INFO, "Homing: Starting slow search.");
					m_torqueLimit = m_homingSearchTorque;
					moveSteps(m_homingBackoffSteps * 2, m_homingUnifiedSps, m_homingAccelSps2);
					m_homingPhase = SLOW_SEARCH_WAIT_TO_START;
					break;
				case SLOW_SEARCH_WAIT_TO_START:
					if (m_motor->StatusReg().bit.StepsActive) m_homingPhase = SLOW_SEARCH_MOVING;
					break;
				case SLOW_SEARCH_MOVING:
					if (checkTorqueLimit()) {
						m_homingPhase = SET_OFFSET_START;
					} else if (!m_motor->StatusReg().bit.StepsActive) {
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

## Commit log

2025-06-16 Added pinch valve, pinch valve motor, mounting plate to assembly
    [NozzleHeadMountingPlate.SLDPRT, PinchValveBase.SLDPRT, PinchValvePlug.SLDPRT]
2025-07-23 electron app!
    [MotorStatusRegister.componentinfo.xml]
2025-09-10 Revert "broke some stuff"
    This reverts commit cf841a8c6ec1ce3907f1707edb84a7e5bdfac082.
    [config.h, fillhead.cpp, gantry.cpp]
2025-10-11 dynamic devices implemented
2025-10-12 working dynamic devices!
2025-11-17 Update generated command files and add gantry command parser
2025-11-17 move gantry to its own repo
2025-11-17 Reorganize repository structure: move libraries to lib folder and flatten fillhead subfolder
    [MotorStatusRegister.componentinfo.xml, insert-big.SLDPRT, insert-small.SLDPRT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]
2025-11-19 Remove script_handlers.py - no longer needed
    - Generic wait_for command handles all 'wait until' functionality
    - Custom handlers no longer supported by equipment control app
    - Simplifies device definition structure

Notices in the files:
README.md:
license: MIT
